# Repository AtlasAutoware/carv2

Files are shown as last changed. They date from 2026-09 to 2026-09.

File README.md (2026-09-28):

# Atlas car v2

The second Atlas Autoware car: a Traxxas Slash 4x4 with a Holmes Hobbies Puller Pro 540 motor, a
SICK TiM561 lidar and a LUCID Triton camera, rebuilt so that almost nothing is wired by hand. Two
custom circuit boards stack on a carbon-fibre-printed deck:

- **Drive board (ATLAS-DRV-1).** The ESC (VESC firmware, same UART commands as car 1), a battery
  protector for a built-in 4S3P 18650 pack, USB-C charging, the servo supply, the lidar's power
  switch and a USB hub.
- **Brain board (ATLAS-BRN-1).** A Jetson Orin Nano carrier forked from Antmicro's open-source
  design, with PoE for the camera and a second Ethernet port for the lidar.

Day to day the car needs one USB-C cable: a 65 W laptop charger charges it, and a laptop on the same
port reaches the Jetson, the ESC and the serial console.

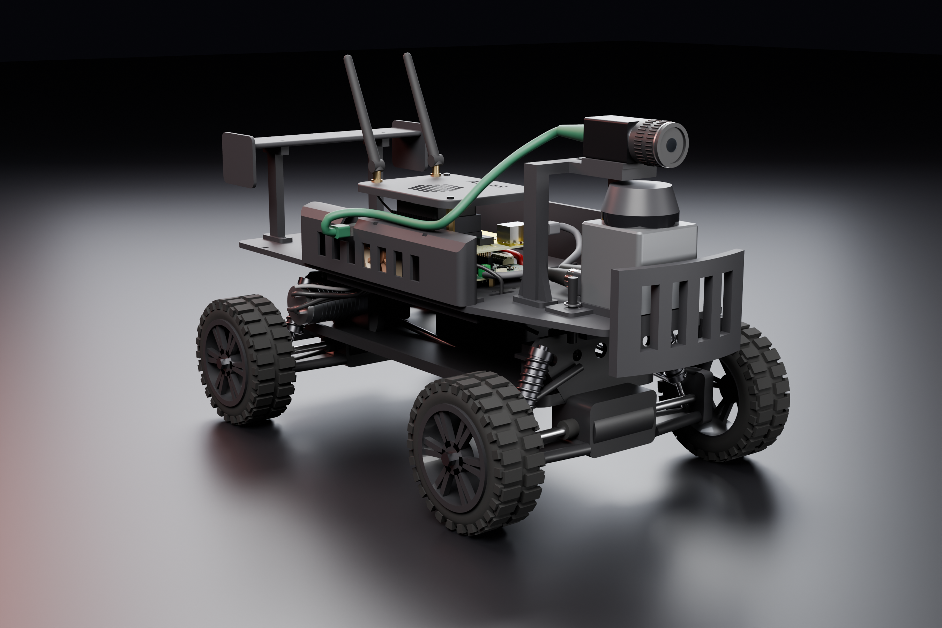
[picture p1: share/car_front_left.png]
car v2, rendered on a stand-in Slash 4x4


## What is in here

| folder | what |
| --- | --- |
| `docs/` | `ARCHITECTURE.md` (the whole design and why), `SOFTWARE.md` (what runs on the boards), `FLASHING.md` (programming the assembled boards), `TPS25751_CONFIG.md` (USB-C charger settings), `PACK_BUILD.md` (building the 18650 pack), `MEASURE_FIRST.md` (chassis numbers to check before printing), `COMPLETE_CAR.md` (the parts that finish the car), `WIRING.md` (every cable run and its length) |
| `boards/drive/`, `boards/brain/` | the two boards: `design.py` is the circuit, `layout.py` the placement and hand-drawn copper, and the KiCad schematics and layouts are generated from them |
| `boards/stack/` | the pin map of the connector between the two boards, used by both |
| `boards/tools/` | the scripts that build, route and check the boards |
| `boards/*/out/fab/` | Gerbers, drill files, pick-and-place and BOM for ordering |
| `firmware/vesc/` | the VESC hardware target for the drive board, `build.sh`, and a prebuilt image in `prebuilt/` |
| `software/jetson/` | the `atlas` command, services and settings for the Jetson (`system/install.sh`), with tests |
| `software/ros2/` | `atlas_power`: battery, E-stop, charging and lidar power in ROS 2 |
| `mech/` | the printed kit: `kit.py` (deck, pods, mounts, pack box) and `extras.py` (stack canopy, bench stand, plugs and cable paths), the STL/STEP files, renders and its own README |
| `sim/` | circuit and thermal checks run on the finished schematics, with their own README |
| `bom/` | the parts list with prices and the cost summary |
| `share/` | pictures for posting; `car_scene.py` and `render_car.py` render the whole car |

## Cost

From `bom/cost_summary.md` (prices from September 2026):

| | USD |
| --- | ---: |
| Drive board: 5 boards, 1 of them assembled | 525.70 |
| Brain board: 5 boards, 1 of them assembled | 563.90 |
| 18650 pack materials | 134.20 |
| Camera lens | 144.00 |
| Charger, cable, fan, thermal pad, hardware, antennas | 124.35 |
| **New purchases** | **1,492.15** |
| Jetson dev kit and NVMe (already on the purchase list) | 459.00 |
| **Car 2 total** | **1,951.15** |
| If needed: M12 camera cable ($30), spot welder ($304.51) | up to 2,285.66 |

The carbon-fibre filament and the aluminium heat spreader (SendCutSend credit) are not in these
numbers because the team already has them.

## Status

On 27 September 2026 the design is finished and nothing has been ordered. Later that day the whole car went into
one model, with every plug and cable. That found two things that could not have been assembled as drawn, now
fixed, and added a canopy over the boards with the Wi-Fi antennas and a bench stand (`docs/COMPLETE_CAR.md`).

- Both boards are routed. KiCad's DRC finds no unconnected nets and no clearance errors on
  either of them. What it still lists is minor: silkscreen warnings on both boards, one 0.2 mm
  track end on the drive board, and on the brain board the footprint-library differences that
  come with Antmicro's design and the courtyard and hole overlaps Antmicro excluded.
- The stack header matches on both boards: all 40 pins carry the same net at the same place, and
  the brain board's corner holes sit over the drive board's (`boards/tools/check_stack.py`).
- The precharge simulation changed the precharge resistors. The bulk capacitors changed too: the
  first choice was tall enough to hit the brain board's SSD (`sim/README.md`).
- The printed kit passes its interference checks. Print the two fit coupons first.

What to check before ordering, and the layout choices that are not obvious from the schematics,
are at the end of `docs/ARCHITECTURE.md`.

## Rebuilding

- Boards: KiCad 10 and Python 3. `boards/tools/run_kicad.sh` runs every step (schematic, board,
  routing export and import, DRC, renders, fabrication files).
  `boards/tools/run_kicad.sh drc-drive fab-drive` checks the finished drive board and writes its
  fabrication files. Careful with `pcb-drive`: it builds the board again from the placement,
  without the routing. The routing itself was done with Freerouting 1.9 and finished with
  `boards/tools/mazeroute.py`.
- Printed kit: `pip install cadquery ezdxf matplotlib`, then `python3 mech/kit.py` and `python3 mech/extras.py`.
- Whole-car renders: `python3 share/car_scene.py`, then `python3 share/render_car.py -- car_front_left car_exploded`
  with Blender 4.2's `bpy` module (Python 3.11, `pip install bpy==4.2.0`) and the board models from
  `run_kicad.sh glb-drive glb-brain`.
- Simulations: ngspice and Python with numpy, scipy and matplotlib; `sim/run_all.sh`.
- Firmware: `firmware/vesc/build.sh` (clones VESC 6.06, adds the two target files, builds; needs
  `arm-none-eabi-gcc`). A build of the committed sources is in `firmware/vesc/prebuilt/`.
- Jetson tools: `sudo software/jetson/system/install.sh` on the car; tests with
  `cd software/jetson && python3 -m pytest tests` (needs `pytest`).

## Licenses

The brain board is derived from Antmicro's Jetson Orin Baseboard (Apache-2.0); its schematic and
board keep Antmicro's notices, and `boards/brain/vendor/antmicro/fetch.sh` downloads the original. The VESC
hardware target is derived from the VESC firmware (GPL-3.0), so those two files are GPL-3.0.

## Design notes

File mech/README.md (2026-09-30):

# Printed kit

The kit is one CadQuery script, `kit.py`. It builds every part and places it on a keep-out model of the
Slash 4x4. Then it checks every pair of solids for overlap, slices the lidar scan plane, exports STEP and STL
(and a DXF for the aluminium heat spreader), and renders PNGs.

`extras.py` builds on it and adds the parts that finish the car: the stack canopy with the Wi-Fi antennas, the
wheels-off bench stand, the mating plugs, and every cable as a path through the model. It checks all of them
against the kit and writes `out/extras_report.json`. The cable lengths from that report are in
`../docs/WIRING.md`, and `../docs/COMPLETE_CAR.md` explains each addition.

    pip install cadquery ezdxf matplotlib
    python3 kit.py                 # about 3 minutes; writes out/ and out/kit_report.json
    UNDER_CLEARANCE=42 python3 kit.py    # any number in P can be overridden the same way
    python3 extras.py              # about 1 minute; canopy, bench stand, plugs and cables, out/extras_report.json

Last run (27 September): zero interference between any two printed parts, bought parts (boards and their tall
components, sensors, cells) or chassis keep-outs. `extras.py` also finds zero between the new parts, the
plugs, the cables and all of those.

Two changes that day came out of modelling the plugs and cables:

- The right side pod's fan moved forward, and a slot through the pod now lets the camera's RJ45 plug out.
- The servo-lead slot in the deck moved clear of the front splice plate.

The only solids that cross the lidar's scan plane (the camera arch legs, the wing, and from `extras.py` the
canopy, its standoffs, the antennas and two cables) sit inside its 90 degree blind sector at the rear. Scan
plane 68.5 mm above the deck, camera axis 122 mm above the deck, pack box inside the battery bay
with 2.8 mm under it. Tightest fit in the board stack: the brain board's NVMe SSD sits 2.4 mm above
the drive board's bulk capacitors.

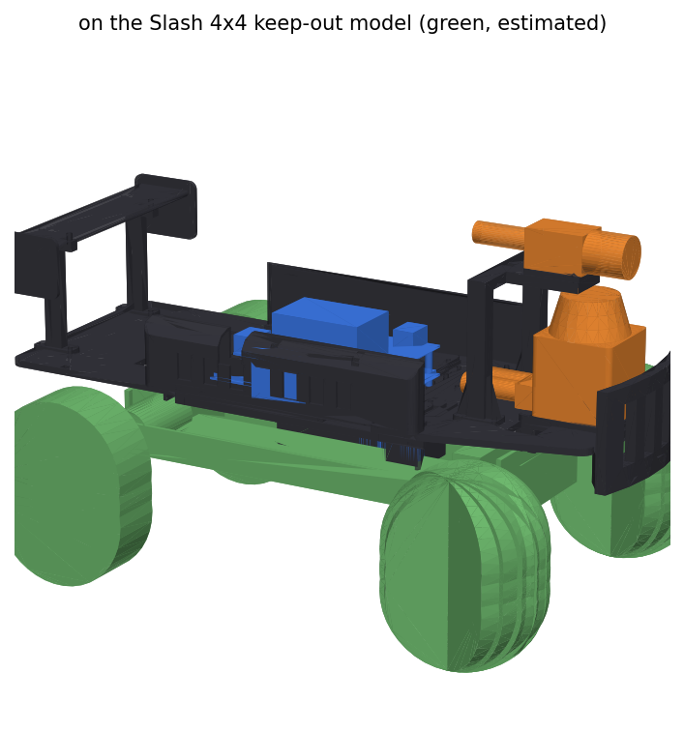
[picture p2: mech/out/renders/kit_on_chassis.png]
kit


## Parts

**Before printing, read [PRINTING.md](PRINTING.md):** several STLs in `out/stl` are not in a printable orientation (the bumper failed on Sept 30). It lists which parts to flip and which need supports.

Sizes are as they sit on the bed (mm). Mass is for solid PETG-CF; with 4 walls and 35 %
gyroid expect about 65 % of it. Everything fits a 250 x 250 bed (Bambu P1S: 256).

| part | print | bed size | solid mass | orientation, notes |
| --- | --- | --- | --- | --- |
| `fit_coupon_front`, `fit_coupon_rear` | 1 each, FIRST | 56-58 x 132 x 25 | 55 / 57 g | top face down, like the deck. Strips of the deck across the towers and body posts: test the saddles and post slots on the real car. Both on one plate: 2 h 30 min, 67 g (P1S, 35 % gyroid) |
| `deck_rear`, `deck_mid`, `deck_front` | 1 each | 146-162 x 178 x 15-25 | 182 / 158 / 171 g | top face down; saddles and ribs point up, no supports. The three pieces butt together and bolt to splice plates underneath |
| `splice_rear_left`, `_right`, `splice_front_left`, `_right` | 1 each | 30 x 72 x 3 | 8 g | flat; 6 x M3 bolts + nylocs each, across the joint |
| `lidar_plinth` | 1 | 70 x 64 x 6 | 24 g | pocket face down; 2 x M3 x 6 into the TiM561's bottom threads (2.0 mm engagement, SICK allows 2.8) |
| `bumper` | 1 | 62 x 124 x 74 | 113 g | flange down; bolts up through the deck into the plinth (4 x M3 x 16) |
| `camera_arch` | 1 | 80 x 102 x 104 | 83 g | feet down; the tongue is a 34 mm bridge |
| `camera_cradle` (0 deg), `_down5`, `_down10` | pick one | 43 x 34 x 4-8 | 7 g | flat; slotted +-1.5 mm for the camera's M3 holes |
| `side_pod_left`, `side_pod_right` | 1 each | 225 x 25 x 50 | 80 / 68 g | outer face down, vents vertical; the right pod holds the 40 mm fan and has the slot the camera plug goes out through |
| `wing_blade` | 1 | 55 x 190 x 46 | 72 g | endplates up |
| `wing_strut_left`, `_right` | 1 each | 35 x 88 x 14 | 16 g | on their side |
| `pack_box` | 1 | 138 x 51 x 72 | 67 g | open end up |
| `pack_lid` | 1 | 138 x 51 x 4 | 27 g | ribs up |
| `cell_holder_bottom`, `_top` | 1 each | 120 x 40 x 5 | 12 g | pockets up |
| `post_washer` | 4 | 30 x 30 x 3 | 3 g | body clips sit on these above the deck |
| `stack_canopy` (extras.py) | 1 | 128 x 99 x 6.4 | 41 g | top face down, no supports; cover over the board stack with the antenna jacks and the fan grille |
| `bench_stand` (extras.py) | 1, PLA | 173 x 123 x 128 | 267 g solid (PETG-CF density) | pad face down; a workshop tool, not on the car |

Total about 1.2 kg solid, about 0.8 kg of filament as printed.

## Material and settings

CF-filled filament is abrasive: use a hardened-steel nozzle (0.4 or 0.6 mm), and dry the
spool first.

| part | material | settings |
| --- | --- | --- |
| deck halves, plinth, arch, wing struts | PETG-CF (or PA-CF if the printer has an enclosure and a dry box) | 0.2 mm layers, 4 walls, 35 % gyroid, 5 top/bottom |
| bumper | PETG-CF; PA-CF is tougher in a crash | 5 walls, 40 % gyroid |
| side pods, wing blade, pack lid | PETG-CF | 3 walls, 20 % gyroid |
| pack box, cell holders | PETG-CF or plain PETG | 3 walls, 30 %; holders at 100 % so the pockets stay round |

Do not rely on CF-filled plastic as electrical insulation: carbon fibre conducts. The pack
has fish paper and Kapton for that.

## Hardware

- M3 brass heat-set inserts (4.0 mm hole, 5 mm deep), about 30 in the deck and the sensor mounts:
  drive board standoffs 6, pack box 6, camera arch 4, side pods 5, wing 4, plinth 4. Buy 50.
- Deck joints: 24 x M3 x 12 socket screws and nylocs through the deck and the four splice plates.
- Board stack: 6 x M3 7 mm male-female standoffs from the deck inserts to the drive board
  (holes H1001-H1004, H1007, H1008), and 4 x M3 20 mm male-female standoffs from the drive board
  to the four corners of the brain board. Over H1002 and H1004 the 20 mm standoff screws through
  the drive board into the 7 mm one below it; over H1005 and H1006 it is held by an M3 nut under
  the drive board. Four M3 x 6 screws on top of the brain board, four more on the drive board's
  other deck holes.
- Heat spreader: 3/16 in (4.76 mm) 6061, 60 x 48 mm, cut from `out/dxf/heat_spreader.dxf`. Order it
  with the four 2.5 mm holes tapped M3. Four M3 x 8 screws come up through the deck into it. The
  notch at one corner makes room for the H1005 nut. A 1.0 mm thermal pad goes between the spreader
  and the bottom of the FETs.
- M3 socket screws 6-16 mm for the rest, and the chassis's own body clips over the post washers.
- Canopy: 3 x M3 40 mm male-female standoffs. They replace the M3 x 6 top screws at three of the brain board's
  corners (brain-local (115.06, 5.06), (6, 84) and (114, 84)); the fourth corner sits under the camera RJ45.
  3 x M3 x 6 button-head screws hold the canopy on them.
- Two RP-SMA antennas and two pigtails from the Wi-Fi card to the canopy, and zip ties (`../docs/WIRING.md`).

## Assembly order

1. Heat-set all inserts. Bolt the three deck pieces to the splice plates.
2. Pack: build it (`docs/PACK_BUILD.md`), drop the box into the bay through the deck window,
   lid on.
3. Deck onto the towers, posts through the slots, washers and body clips on.
4. Lidar screwed to the plinth on the bench; plinth, deck and bumper bolted together from
   below.
5. Camera arch, cradle, camera.
6. Heat spreader (screwed to the deck from below) and thermal pad, 7 mm standoffs, drive board.
   Wire the lidar power terminal (J902) now: its screws end up under the brain board's front edge.
7. 20 mm standoffs, then the brain board. Clip the two Wi-Fi pigtails onto the M.2 card before the Jetson
   module goes on, because the card sits under it.
8. Side pods, fan, wing. Plug in the list in `docs/ARCHITECTURE.md`; the camera plug goes out through the slot
   in the right pod. The runs are in `docs/WIRING.md`.
9. The 40 mm canopy standoffs, then the canopy, with the pigtails' RP-SMA jacks nutted into its two holes.
   Screw the antennas on last.

## What the model does not know

Every chassis dimension is an estimate carried over from car 1 until it is measured
(`docs/MEASURE_FIRST.md`). The camera's bottom hole spacing is an estimate. The TiM561's
swivel-unit and plug sizes are estimates (the SICK drawing does not give them).

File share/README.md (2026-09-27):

# Pictures for posting

All of these come out of the design files; none are photos.

| file | what it shows |
| --- | --- |
| `car_front_left.png`, `car_rear_right.png`, `car_side.png`, `car_top.png` | The whole car: the printed kit with the stack canopy, both boards, the pack, every cable and plug, on a stand-in Slash 4x4. Rendered with Blender Cycles by `render_car.py` from the scene `car_scene.py` builds out of `mech/kit.py`, `mech/extras.py` and the two boards' KiCad 3D models. |
| `car_exploded.png` | The same, with the drive board lifted 55 mm, the brain board 115 mm and the canopy 185 mm to show the stack. The cables are hidden in this one, and the antennas are folded back. |
| `drive_iso.png`, `drive_top.png`, `drive_bottom.png` | The drive board as routed, rendered by KiCad. The four bulk capacitors, the 2 x 20 stack socket and the power stage (FETs on the underside) are the big parts. |
| `brain_iso.png`, `brain_top.png` | The brain board (Jetson carrier) as routed, rendered by KiCad. The Jetson module and the NVMe card plug in and are not shown. Many of the parts from Antmicro's design, the module socket among them, have no 3D model here and show as bare pads. |
| `drive_thermal_70A.png` | Simulated temperature of the drive board at 70 A peak phase current with the fan, 35 C air: about 58 C on the hottest FET (`sim/drive_thermal.py`). |
| `dclink_waveforms.png` | Simulated ripple current in the ESC's bus capacitors (`sim/dclink.py`). |
| `precharge.png` | Simulated switch-on of the motor bus through the precharge resistors (`sim/precharge.py`). |
| `poe_boost.png` | Simulated 52 V boost that powers the camera over Ethernet (`sim/poe_boost.py`). |

Stand-ins: in the car pictures the chassis is drawn from `kit.py`'s keep-out numbers (all estimates), with
suspension, wheels and tread drawn to look plausible, not measured. The lidar, the camera and lens, the Jetson
module with the dev kit's heatsink and fan, the NVMe and Wi-Fi cards, the RJ45 jacks and plugs, the stacking
header, the 40 mm fan and the antennas are simple shapes sized from their datasheets or from kit.py's envelopes, not models of
the real parts. In the drive board pictures a few parts have no 3D model in KiCad and show as bare pads.

To make them again:

1. `boards/tools/run_kicad.sh glb-drive glb-brain render-drive render-brain` writes the board models and renders
   to `boards/*/out/render/`; copy the board PNGs you want here.
2. `python3 share/car_scene.py` writes the scene (`share/scene/`, not in git).
3. Render with `python3 share/render_car.py -- car_front_left car_rear_right car_side car_top car_exploded`, using
   Blender 4.2's `bpy` module (Python 3.11). About 12 minutes a view at 2700 x 1800 and 80 samples on two CPU
   cores; `--quick` gives a 900 x 600 preview in under a minute.
4. `sim/run_all.sh` writes the plots to `sim/out/`.

`make_renders.py` is the older VTK version, with no chassis, canopy or cables. It writes the same car file names.

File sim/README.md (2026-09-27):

# Simulations

Checks run on the finished schematics, before anything is ordered. Each one is a short script; `run_all.sh`
runs them all (ngspice and Python with numpy, scipy and matplotlib) and writes the plots and a JSON file per
check to `out/`. Two of them changed the design; the changes are listed at the end.

| script | question | answer |
| --- | --- | --- |
| `dclink.py` | How much ripple current do the ESC's bus capacitors carry? | 3.5 A per capacitor at 30 A peak phase current, 7.6 A at 70 A, 10 A at 100 A. The 12 ceramics take 8-27 A between them, the battery leads about 2 A. |
| `precharge.py` | Does the precharge resistor survive switching the car on? | One 10 Ohm 2512 resistor took 0.29 J in about 10 ms, about 1.5 times its single-pulse rating. Two pulse-proof 22 Ohm resistors in parallel take 0.15 J each, inside theirs. |
| `poe_boost.py` | Is the camera's 52 V supply comfortable at full load? | Inductor peak 0.75 A with the camera (5 W) and 1.6 A at 15 W, against 4.2 A saturation and about 2.4 A current limit. 52 V ripple 80 mV at 5 W, 250 mV at 15 W. |
| `drive_thermal.py` | How hot does the drive board get? | At 70 A peak phase current with the fan: about 58 C on the hottest FET at 35 C air; 70 C at 100 A. Without the fan, 91 C at 70 A. |

## What the numbers rest on

- **Bus ripple (`dclink.py`).** Three ideal half-bridges switch at 30 kHz with sine-triangle PWM, modulation
  0.8, into a motor modelled as 10 mOhm + 20 uH per phase with a sinusoidal back-EMF at 400 Hz. The
  Puller Pro's phase resistance and inductance are not published; 20 uH is typical for a 540-size motor
  and mostly sets the switching ripple in the phase current, not the capacitor current. Capacitors:
  Panasonic EEH-ZU1V331P (330 uF, 11 mOhm, rated 4.8 A rms at 100 kHz and 125 C), twelve Murata
  GRM32ER71H106KA12L (10 uF 50 V X7R, about 6 uF each left at 14 V). Pack 24 mOhm with 150 nH of leads.
- **Precharge (`precharge.py`).** Full pack (16.8 V), 1.4 mF on the bus, and the servo supply switching on
  above 9 V and drawing 0.3 A, which holds the bus about 3 V below the pack until the main FETs close.
  The pulse rating comes from the single-pulse diagrams of the Vishay CRCW-HP series (about 100 W for 1 ms,
  20 W for 10 ms, 2 W for 100 ms, 2512 size) and of IRC's PWC series for a standard part (about half).
- **Boost (`poe_boost.py`).** The power stage only, at the duty cycle that holds 52 V: 47 uH Coilcraft
  XAL7070-473 (84 mOhm), CSD19538Q3A (60 mOhm taken hot), Vishay SS2H10, 3 x 2.2 uF 100 V ceramics (about
  0.9 uF each at 52 V) and a 22 uF aluminium can. The LM5155's loop is not simulated: its datasheet does not
  publish the internal gains a switching model would need. The compensation follows TI's design
  procedure (crossover about 5 kHz). Switching losses are left out, so the efficiency figure in the JSON
  file counts conduction losses only.
- **Temperature (`drive_thermal.py`).** A 0.5 mm grid over the 140 x 90 mm board: in-plane conduction from
  six 2 oz copper layers (90 % copper under the power stage, 50 % elsewhere) and FR4, both faces cooled by
  the side-pod fan's air (h = 25 W/m2K; 8 W/m2K for still air), and the aluminium spreader under the power
  stage coupled through the thermal pad and the FET package tops (taken as 20 C/W). Losses at the chosen
  operating point: FET conduction from the switch RMS currents with 1.2 mOhm hot, switching from
  56 ns edges (2 x 28 nC Qgd at 1 A gate drive), dead-time diode loss, the battery-path FETs and shunts,
  and about 2 W for the rest of the board. 70 A peak phase current is about 33 A from the pack.

These are estimates to find weak spots before building. The bench checks in `docs/ARCHITECTURE.md` (FET
and capacitor temperatures at 50 A and 70 A) still stand.

## Design changes they led to

1. **Precharge resistor.** R319 was one 10 Ohm 2512. It is now R319 + R320, two 22 Ohm Vishay CRCW2512-HP
   pulse-proof resistors in parallel, R320 directly under R319 on the bottom. The STM32 firmware also gives
   up on a precharge whose bus is still under 4 V after 10 ms (a short on the motor bus), because the
   resistors are rated for the charging pulse, not for 13 W each for as long as the old 1 s timeout
   (`firmware/vesc/hw_atlas_drv1.c`).
2. **Bus capacitors.** The 470 uF 35 V part turned out to be 16.8 mm tall, which would hit the brain
   board's NVMe SSD. The 330 uF 35 V part of the same series is 12.8 mm tall (2.4 mm clear of the SSD).
   The simulation shows why capacity matters less than ripple current here: at 70 A peak phase current each
   of the four capacitors carries about 7.6 A rms, above the 4.8 A rated at 125 C. That rating is set at
   the capacitor's maximum temperature; at 35-55 C board temperature they will run warm, not fail. Worth a
   thermocouple on one of them during the 70 A bench run.

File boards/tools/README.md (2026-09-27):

# Board tools

These scripts turn `design.py` and `layout.py` into finished KiCad boards. Some of them run inside
KiCad's Python (`flatpak run --command=python3 --filesystem=home org.kicad.KiCad script.py ...`, marked
**K** below). The rest need plain Python with numpy, scipy, shapely, scikit-image and matplotlib
(`pdfpads.py` also needs PyMuPDF). `run_kicad.sh` wraps the KiCad steps, one argument per step:
`run_kicad.sh drc-drive fab-drive`, `run_kicad.sh render-brain` and so on. It works from the folder
it sits in; a first argument ending in `.tar.gz` is a sync tarball in `.work/` to unpack first.
`pcb-<board>` builds a board again from its placement, so on a routed board it throws the routing away.

## Order of work

1. **Schematic.** `build_sch.py` writes the schematic and the parts JSON. It uses `eda.py` for
   schematic capture and `chips.py` for the pin tables. `check_fp.py` checks that every footprint
   exists with the right pads.
2. **Placement.** `placer.py` runs the board's `layout.py` against a footprint model, then places
   the remaining parts next to the pins they connect to. The drive board's layout sets `KEEP_AUTO`
   now that it is routed, so the other parts stay put when one part is moved. The brain board's
   layout pins its parts by hand instead.
3. **Board.** `build_pcb.py` (**K**) builds the board from the placement and the hand-drawn copper
   in `layout.copper()`: escapes, via arrays and pours. `check_copper.py` checks that copper before
   KiCad sees it.
4. **Autorouting.** `dsn_export.py` (**K**) and `dsn_patch.py` feed Freerouting, and
   `ses_import.py` (**K**) brings the result back. `route_prep.py` holds the view of the board that
   the router sees.
5. **Finishing the routing.** `dump_board.py --route-view` (**K**) writes the board to JSON.
   `mazeroute.py` then routes what is still open: coupled differential pairs first, then everything
   else in negotiated rounds. It works on the dump and writes a routes JSON, which `add_routes.py`
   (**K**) applies. Its docstring lists the options.
   - `strip_routes.py` and `strip_box.py` (**K**) take routed copper off so it can be routed again.
   - `move_parts.py` (**K**) moves parts on a routed board to their new placement.
   - `update_zone.py` (**K**) gives a pour a new outline.
   - `zone_islands.py` (**K**) lists which pieces of a pour touch what.
   - On the drive board, the last few ground pads left in islands of the outer ground fill were
     joined by hand: a via or a short track each, checked for clearance before it went on. The board
     file holds the result.
6. **Finish.** Run these in order, then run DRC (`drc-<board>`); it should show no unconnected
   items and no clearance errors.
   - `pad_vias.py` (**K**) gives each unconnected pad a via into its plane. Other modes:
     - `--ep REF.PAD` adds a via grid inside exposed pads.
     - `--pads` works on pads you name.
     - `--through-pours` lets a via go through another net's pour.
     - `--zone-islands` gives stray pieces of pour a via.
   - `finish_pcb.py` (**K**) adds GND stitching vias, cleans up the silkscreen and swaps in 3D models.
   - `clean_tracks.py` (**K**) splits T-joins and tracks that run on past a via or pad, then removes
     dead-end tracks and vias, including vias that only join tracks on one layer.
   - `set_netclasses.py` writes the net classes into the project file.
7. **Outputs.** `run_kicad.sh fab-<board>` writes Gerbers, drill files, CPL and BOM.
   `render-<board>` and `glb-<board>` write the pictures and the 3D model.
   `check_stack.py` checks the connector between the two boards.

The brain board starts from Antmicro's board rather than step 3: `fork_pcb.py` (**K**) deletes the
removed parts, renets the rest and places the new ones.

## Helpers

- `plot_geom.py` and `plot_copper.py` plot a placement and the hand-drawn copper.
- `fpinfo.py` prints a footprint's pads.
- `pdfpads.py` reads pad sizes off TI land-pattern PDFs, for `make_footprints.py`.
- `sexp.py` reads and writes KiCad files.
- `pack_sync.sh` packs the sources for the KiCad machine. It is specific to how these boards were
  built and has a hard-coded path (the build container's copy of the repo).

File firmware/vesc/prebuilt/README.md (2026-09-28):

# Prebuilt ATLAS_DRV1 firmware

Built by `firmware/vesc/build.sh --system` from the commit named in `BUILD_INFO.txt`. Not yet
run on a board.

- `atlas_drv1_full.hex`: firmware (0x08000000) + VESC bootloader (0x080E0000). The first flash
  of a blank STM32, over SWD (docs/FLASHING.md, step 1). Needed once so that VESC Tool can
  update the firmware later.
- `atlas_drv1.bin`: the firmware alone, for VESC Tool (Firmware, Custom File).

Rebuild after any change to `hw_atlas_drv1.c` or `.h` and replace these files.

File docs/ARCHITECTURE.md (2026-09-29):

# Car v2: integrated electronics and printed kit

Design for the second Atlas car on the Traxxas Slash 4x4 (6822 chassis, the one with the
"KA2246-R00" label and the Holmes Hobbies Puller Pro 540 2200 kV motor). The aim: plug in as
few things as possible. Everything that can live on a circuit board does, the battery is
built in and charges over USB-C, and the body is printed in carbon-fibre filament in the
style of the Neobotics NeoRacer.

Status on 2026-09-27: see [Status and next steps](#status-and-next-steps) at the end. In short,
both boards are designed and routed and pass KiCad's DRC with no unconnected nets and no
clearance errors; the printed kit is modelled and checked; nothing has been ordered.

## What you plug in

Once, when building the car:

| connection | to | how |
| --- | --- | --- |
| 18650 pack, power | drive board B+ / B- pads | two 10 AWG leads, soldered |
| 18650 pack, cell taps + temperature | drive board | one 7-pin JST-XH |
| motor phases | drive board | three 12 AWG pigtails soldered to the board, 4 mm bullets to the motor |
| motor hall sensor | drive board | the motor's own 6-pin sensor lead (JST-ZH assumed, confirm on the motor) |
| steering servo | drive board | the servo's own 3-pin lead |
| lidar power | drive board | the donor M12 power cable into a 2-pin terminal |
| lidar Ethernet | brain board RJ45 #2 | the donor M12-D to RJ45 cable |
| camera | brain board RJ45 #1 | one M12 X-coded to RJ45 cable: data and PoE power together; the plug goes out through the slot in the right side pod |
| Jetson fan, side-pod fan | brain board / drive board | their own leads |
| Wi-Fi antennas | M.2 Wi-Fi card | two MHF4 pigtails to the RP-SMA jacks in the stack canopy (the dev kit's AW-CB375NF card has MHF4 jacks) |
| E-stop loop (optional) | drive board | 2-pin JST-PH, normally closed; a jumper if unused |

Every run, its length and its route are in `docs/WIRING.md`. The parts that finish the car (the stack canopy,
the bench stand, and the fixes that came out of modelling the plugs) are in `docs/COMPLETE_CAR.md`.

Every day: **one USB-C cable.** A 65 W USB-C charger charges the car. A laptop on the same
port reaches the Jetson (USB networking and flashing), VESC Tool on the ESC and the Jetson's
serial console, and keeps the car alive while you work.

Compared with car 1, this removes the XT90 Y-harness, the separate ESC and its USB lead, the
PD trigger cable and barrel jack, the power bank, the BEC and its fused tap, the PCA9685 board,
the USB hub and every USB sensor cable. The two boards plug into each other.

## System

```mermaid
flowchart LR
  subgraph PACK["4S3P 18650 pack (12 x Molicel P28A, 8.4 Ah)"]
    CELLS["cells + nickel"]
  end
  subgraph DRV["drive board ATLAS-DRV-1 (140 x 90 mm, 6 layers, 2 oz)"]
    BMS["BMS BQ7791508<br/>low-side FETs, 0.5 mOhm sense"]
    CHG["USB-C PD TPS25751D<br/>+ charger BQ25798"]
    SW["main switch TPS48111<br/>precharge, 1.2 us short-circuit cut"]
    BTN["power latch<br/>SN74LVC1G74 + TPS70933"]
    ESC["ESC: STM32F405 + DRV8323RS<br/>12 x CSD18510Q5B, VESC firmware"]
    SRV["servo 7.5 V 8 A<br/>TPSM63610"]
    LID["lidar eFuse TPS26600 1 A"]
    HUB["USB2514B hub + CP2102N"]
    IMU["LSM6DS3TR-C IMU"]
  end
  subgraph BRN["brain board ATLAS-BRN-1 (Jetson carrier, 120 x 90 mm, 8 layers)"]
    EF["input eFuse TPS259474"]
    SOM["Jetson Orin Nano module<br/>on SO-DIMM"]
    NVME["M.2 NVMe"]
    WIFI["M.2 Wi-Fi"]
    POE["52 V boost LM5155<br/>+ PoE PSE TPS23861"]
    LAN["LAN7800 USB-to-Ethernet"]
  end
  CELLS --> BMS --> SW --> ESC --> MOTOR["Puller Pro 540<br/>2200 kV, halls"]
  SW --> SRV --> SERVO["INJS235 servo"]
  BMS --> CHG
  USBC["USB-C: charger or laptop"] --> CHG
  USBC --> HUB
  CHG -- "VSYS 12-16.8 V" --> EF --> SOM
  CHG -- VSYS --> LID --> TIM["SICK TiM561"]
  EF --> POE --> CAM["LUCID Triton<br/>PoE, GigE"]
  SOM -- "GbE" --> CAM
  SOM -- "USB 2" --> LAN --> TIM
  HUB -- "USB 2" --> SOM
  HUB --> ESC
  SOM -- "UART 115200" --> ESC
  BTN --> SW
  IMU --> ESC
```

Why two boards and not one: the ESC and battery path need thick copper (2 oz) and carry
70-150 A; the Jetson carrier needs eight layers with impedance-controlled pairs for PCIe and
USB and fine pitch for the 260-pin module socket. One board would have to be both, which makes
the whole thing expensive and hard to route. Stacked, they plug together through a 2 x 20
header with no wires, each can be tested alone, and if the carrier has a bug the Jetson module
goes back on its NVIDIA dev-kit carrier while the drive board keeps running the car.

## Power budget

| load | power | source |
| --- | --- | --- |
| Jetson Orin Nano module, 25 W mode, + carrier losses | about 27.5 W | NVIDIA power modes; 10 % carrier loss assumed |
| NVMe SSD | about 3.5 W peak | typical M.2 NVMe |
| Wi-Fi card | about 2 W | typical |
| LAN7800 | about 1 W | typical |
| SICK TiM561 | 4 W typical | SICK datasheet 1071419 |
| LUCID Triton over PoE | 3.1 W at the camera, about 4 W with the boost and PSE losses | Edmund Optics listing for TRI023S-CC |
| drive board logic, fans | about 3 W | estimate |
| **compute rail total** | **about 45 W: 3.1 A at 14.4 V, 3.7 A at 12 V** | |
| motor | 70 A continuous, about 150 A bursts | team's own logs |
| servo | 7.5 V, up to 8 A (10 A peak) | TPSM63610 rating |

Pack: 4S3P Molicel P28A = 14.4 V nominal, 16.8 V full, 8.4 Ah, about 121 Wh, 105 A maximum
continuous (35 A per cell, 18650batterystore.com). That is above 100 Wh, so flying with it
needs airline approval (the 100-160 Wh class). With the car parked and everything on (45 W)
it runs about 2.5 hours; driving time depends on how hard the motor works.

Charging: the BQ25798 accepts 3.6-24 V at up to 3.3 A on VBUS and charges at up to 5 A
(BQ25798 datasheet, recommended operating conditions). The input limit is set to 3.25 A, so a
65 W charger at 20 V is the most it can use. With the car off, about 60 W goes into the pack:
roughly 2.5 hours from empty. With the car on, the compute rail takes about 45 W of the 65 W, so
the pack charges slowly while you debug. A laptop port (5 V, 7.5-15 W) keeps the car alive on
the bench but will not fully charge it.

## Drive board (ATLAS-DRV-1)

140 x 90 mm, 6 layers, 2 oz copper on every layer, ENIG. Sources in `boards/drive/`: `design.py` is the
circuit (every part with the reason for its value), `layout.py` the placement and the
hand-drawn copper, and the KiCad files are generated from them. The board stands on six 7 mm
standoffs on the printed deck. The ESC power stage is on its underside and presses through a
1 mm thermal pad onto an aluminium heat spreader, with a 40 mm fan in the right side pod
blowing across it.

**Battery protection.** TI BQ7791508: a 3-5S protector that needs no microcontroller, with
cell balancing. This variant trips at 4.20 V over-voltage and 3.00 V under-voltage per cell,
over-temperature 65 C, and recovers from current faults on its own. It drives low-side charge
and discharge FETs (4 + 4 CSD18510Q5B) in the pack's negative lead. Its current thresholds are
voltages across the sense resistor, so the 0.5 mOhm four-terminal shunt (Isabellenhuette BVR,
4026) sets them: OCD1 70 mV = 140 A for 1.4 s, OCD2 140 mV = 280 A for 0.7 s, short circuit
300 mV = 600 A for 0.4 ms, charge over-current 60 mV = 120 A. The VESC input-current limit
(90 A) keeps normal driving under OCD1.

**Main switch and precharge.** A TI TPS48111 high-side driver switches the motor bus through
four CSD18510Q5B, with a 0.2 mOhm shunt. The STM32 sequences it: first the precharge FET, which
charges the ESC capacitors through two pulse-proof 22 Ohm resistors in parallel (time constant
about 16 ms), then, once the bus voltage has come up, the main FETs. No spark and no BMS
short-circuit trip at switch-on. If the bus is still under 4 V after 10 ms, something on it is
shorted, and the firmware gives up rather than cook the resistors. The TPS48111 cuts a
short circuit (350 A) in 1.2 us and an overload (150 A for 10 ms) on its own, retries after
15 s, and reports the bus current to the MCU.

**Power button.** A TPS70933 LDO keeps a 3.3 V always-on rail from the pack (1 uA). An
SN74LVC1G74 flip-flop is the on/off latch: a press of the on-board button (or a remote button
on the 2-pin connector) sets it, which turns on the main switch and the 5 V buck. The MCU turns
the car off by clearing the latch (KILL, PB12), after the Jetson has shut down. A crash or reset
of the MCU does not turn the car off. The same press wakes the charger out of ship mode.

**USB-C charging.** TI TPS25751D USB PD controller (integrated sink switch) plus TI BQ25798
buck-boost charger. The TPS25751D loads its configuration from a 64 KB I2C EEPROM (M24512),
negotiates up to 20 V and programs the BQ25798 over I2C with no MCU. The EEPROM image is made
with TI's Application Customization Tool (settings in `docs/TPS25751_CONFIG.md`), and the Jetson
writes it through the controller's own I2C port (`atlas pd flash`); the 4-pin header J702 stays unfitted. The
BQ25798 is set for 4S and 1.5 MHz by its PROG resistor, with the input limit at 3.25 A. Its
SYS output (NVDC power path) is the compute rail, VSYS, so the Jetson and the lidar run from
USB power whenever it is plugged in. The pack's NTC goes to the BMS; the charger's TS input sees
a fixed 25 C divider.

**One cable for debugging.** The USB-C data pins go to a Microchip USB2514B hub. Port 1: the
Jetson's USB0 (L4T USB networking at 192.168.55.1). Port 2: the STM32's USB (VESC Tool).
Port 3: a CP2102N bridge to the Jetson's debug UART (boot log and console). A FLASH slide
switch and two TS3USB30E switches connect the USB-C port straight to the Jetson's USB0
instead, because NVIDIA asks for a direct link in recovery mode. These five high-speed links
are routed as coupled pairs (0.15 mm tracks, 0.15 mm gap, 0.2 mm to everything else). The
width for 90 Ohm depends on the stack-up actually ordered, so check it in JLCPCB's impedance
calculator before ordering and ask for impedance control.

**ESC.** A VESC-6-class design: STM32F405RGT6 and TI DRV8323RS gate driver (three
current-sense amplifiers, gain 40 V/V, and a small buck that makes the board's 5 V), twelve
CSD18510Q5B (40 V, 0.79 mOhm typical at 10 V; TI datasheet SLPS632), two per switch, three
0.2 mOhm low-side shunts (range +-206 A), 4 x 330 uF hybrid polymer bulk capacitors plus
12 x 10 uF ceramics next to the FETs. Conduction loss at 70 A with the FETs hot
(1.5 x Rds(on)): 3 x 70^2 x 0.6 mOhm = about 9 W, plus a few watts of switching. The board
keeps the Trampa HD60 pin map on purpose, so the firmware change is small:
`firmware/vesc/hw_atlas_drv1.{h,c}` (derived from `hw_hd60`, GPL-3.0). The changes: the IMU's
SDA moves off PB2 so BOOT1 stays low for the ROM bootloader, the power-hold pin becomes KILL,
and PA4-PA7, PC10, PC14 and PC15 carry the new brain-power, current, precharge, E-stop and
Jetson-handshake signals. The target builds with the VESC 6.06 tree (`firmware/vesc/build.sh`). The Jetson talks to it on
USART3 at 115200 baud, the same as car 1, so `vesc_driver` does not change.

**Other outputs.** Servo: TI TPSM63610 power module (integrated inductor, 8 A, 10 A peak) set
to 7.5 V from the switched motor bus, on above 9 V, with 4 x 47 uF plus 220 uF polymer on its
output for stall pulses; the signal comes from the VESC servo output through a 5 V buffer.
Lidar: TI TPS26600 eFuse at 1 A from VSYS into a 2-pin terminal, off until the Jetson enables
it, so the Jetson can power-cycle the lidar. Fan: 5 V, 4-pin header, full speed.

**Sensing and safety.** LSM6DS3TR-C IMU on the VESC's bit-banged I2C (the VESC `lsm6ds3`
driver). TI INA228 on the BMS shunt gives the Jetson pack voltage, current and energy over I2C.
SN65HVD230 for a spare CAN port with a termination jumper. E-STOP: a normally-closed 2-pin loop
AND-ed in hardware (74LVC1G08) with the MCU's gate-enable pin into the DRV8323's ENABLE, so
opening the loop (a big red button or a wireless relay) stops the motor even if the firmware
is hung.

## Brain board (ATLAS-BRN-1): the Jetson carrier

120 x 90 mm, 8 layers, impedance-controlled, ENIG. It is a fork of Antmicro's open-source
Jetson Orin Baseboard (github.com/antmicro/jetson-orin-baseboard, Apache-2.0, 120 x 60 mm):
the hard high-speed layout around the module socket, the M.2 slots and the module supply is
kept exactly as Antmicro routed it, and the board grows by a 30 mm strip for the new circuits.
`boards/brain/fork_config.py` lists every change; `fork.py` and `tools/fork_pcb.py` apply them
to Antmicro's schematic and board.

Kept: SO-DIMM module socket, module power section, M.2 Key M (2280 NVMe), M.2 Key E (Wi-Fi),
the RJ45 with its magnetics, RTC backup, fan header, reset and recovery buttons, the I/O
expander.

Removed: both CSI camera connectors (the camera is GigE), HDMI, the USB-C debug/DisplayPort
port and the USB 3 USB-C port with their PD controller (charging and USB live on the drive
board), the DC barrel input, the PoE powered-device front end, and the expansion socket.

Added:
- **Board input.** A TPS259474 eFuse takes VSYS from the stack header when the drive board
  raises POWER_EN, limits it to 5 A, turns off above 19.2 V and soft-starts the module supply.
- **PoE for the camera.** A TI LM5155 boost makes 52 V from VSYS (300 kHz, 47 uH Coilcraft
  XAL7070, CSD19538Q3A switch), and a TI TPS23861 IEEE 802.3at PSE, running in its automatic
  mode, powers port 1 on the centre taps of the RJ45 that already carries the module's Gigabit
  Ethernet. The Triton needs IEEE 802.3af and draws 3.1 W. This replaces the AC PoE injector
  the camera needed.
- **Second Ethernet for the lidar.** A Microchip LAN7800 USB-to-Gigabit bridge on the module's
  USB 2 pair (the one Antmicro used for the USB-C port), with its own RJ45. The TiM561 is
  100BASE-TX; the stock L4T kernel has the `lan78xx` driver. The chip is turned so its
  Ethernet pins face the jack: the four pairs run straight to it as 100 Ohm pairs and the USB 2
  pairs as 85 Ohm pairs, with the widths and gaps Antmicro set for this stack-up.
- **Stack header.** 2 x 20, 2.54 mm long-pin header on the underside mating the drive board's
  socket. The module's UART is 1.8 V, so an NTS0102 shifts it to the STM32's 3.3 V. The
  expander pins that drove the removed camera and USB-C switches now carry the drive board
  signals (STM32 reset and BOOT0, lidar enable, E-stop and charger status).

The module from the Orin Nano Super dev kit moves over with its heatsink and fan. The
dev-kit carrier stays in the drawer as the fallback.

## Stack header (drive board to brain board)

The brain board stands 20 mm above the drive board on four M3 standoffs, one at each corner.
The connector is a Samtec SSQ-120-03-G-D socket on the drive board and a TSW-120 long-pin
header on the brain board. `boards/stack/stack.py` defines the pin map once for both boards;
`boards/tools/check_stack.py` checks both finished boards against it (nets, pin positions, and
that each brain-board corner hole sits over a drive-board hole).

| pins | signal | direction | note |
| --- | --- | --- | --- |
| 1-6 | VSYS | drive to brain | 12-16.8 V, 6 pins x 3 A |
| 7-10, 13-14, 29-30, 36-40 | GND | | |
| 11, 12 | USB0 D+ / D- | both | Jetson USB0: hub port 1, or straight to USB-C when flashing |
| 15, 16 | VESC UART | Jetson UART1 to STM32 USART3 | 115200 baud, 3.3 V, vesc_driver |
| 17, 18 | console UART | Jetson debug UART to the CP2102N | 3.3 V |
| 19, 20 | I2C SCL / SDA | Jetson I2C1 | INA228, board ID EEPROM, TPS25751 |
| 21 | PWR_BTN_N | drive to brain | power button: the Jetson shuts down |
| 22 | OS_HALTED | brain to drive | high once the module is off; the MCU may cut power |
| 23 | POWER_EN | drive to brain | turns on the brain board's input eFuse |
| 24 | MCU_NRST | brain to drive | the Jetson can reset the STM32 (open drain) |
| 25 | MCU_BOOT0 | brain to drive | the Jetson can start the STM32 bootloader |
| 26 | ESTOP_OK | drive to brain | E-stop loop closed |
| 27 | CHG_STAT | drive to brain | low while charging |
| 28 | LIDAR_EN | brain to drive | TPS26600 enable |
| 31, 32 | spare | | brain-board expander pins; test pads on the drive board |
| 33, 34 | CAN TX / RX | Jetson CAN | 3.3 V; test pads on the drive board |
| 35 | 3V3_DRV | drive to brain | reference for the level shifters |

## The pack

Twelve Molicel P28A (18.6 x 65.2 mm, 46 g) standing upright in a 2 x 6 grid, 4S3P, inside a
printed box in the stock battery bay. With the first and last groups flipped, both main
terminals come out on top, so the leads go straight up through the lid to the drive board.
Details, strip layout and safety: `docs/PACK_BUILD.md`.

## Software changes

Details in `docs/SOFTWARE.md`; programming order in `docs/FLASHING.md`.

- ESC: `firmware/vesc/build.sh` builds the `fw_atlas_drv1` target on VESC 6.06 (it compiles; not
  yet run on a board). First flash over SWD with an ST-Link, then updates from VESC Tool over USB.
  `vesc_driver` keeps working over the UART at 115200 (`/dev/atlas_vesc`).
- Lidar: SICK's `sick_scan_xd` ROS 2 driver supports the TiM5xx family over Ethernet; the
  TiM561 ships at 192.168.0.1. The Jetson's lidar port is set to 192.168.0.100/24.
- Camera: LUCID's Arena SDK and `arena_camera_ros2`. The camera port runs link-local with jumbo
  frames (MTU 9000).
- IMU: now from the ESC (`vesc_driver` IMU topic) instead of the OAK-D.
- Battery: atlas-battery.service reads the INA228 and keeps a state-of-charge estimate;
  the `atlas_power` ROS 2 node publishes it as `/battery`, with `/estop_ok` and `/charging`.
- Power button: logind shuts the OS down on the power-key event; the drive board then cuts power.
- Charger: the TPS25751 EEPROM image, made once with TI's Application Customization Tool and
  written from the Jetson (`atlas pd flash`).

## Safety

- The BMS works without firmware and sits between the cells and everything else. The main
  switch adds a second, faster short-circuit cut. The E-STOP loop cuts gate drive in hardware.
- There is no fuse between the cells and the BMS FETs, so the pack wiring itself is only as
  safe as its insulation: fish paper on every positive cap, Kapton over every strip, lid on.
- Carbon-fibre-filled filament can conduct at the surface. Never let it be the only
  insulation between two conductors.
- Build and first-charge the pack with an adult supervising, on a non-flammable surface.
- Check the ESC's temperature at 50 A and then 70 A on the bench before racing.

## Why there is no FPGA

The measured bottleneck on car 1 is CPU load (81-90 % on every core with the full stack).
The Jetson's GPU can take the heavy CPU work (the particle filter's ray casting already has a
CUDA implementation), and the STM32 already runs the real-time motor, servo and IMU loops. A
custom RISC-V FPGA would add power, cost and months of design for work the GPU does better.
If a real accelerator need appears later, an off-the-shelf FPGA card (LiteFury or Acorn,
Artix-7 on M.2, which can run open-source RISC-V cores) fits the M.2 slot with no board
change.

## Status and next steps

**Done, 27 September 2026.**

- Drive board: 408 footprints on 6 layers, routed with Freerouting, then
  `boards/tools/mazeroute.py`, with the power copper drawn by hand in `layout.py`. DRC: no
  unconnected nets, no clearance errors. It still warns about silkscreen clipped by the board edge
  (6), one reference over copper, and one 0.2 mm piece of track at a corner of a USB pair that it
  calls open (the piece overlaps the rest of the track).
- Brain board: DRC shows no unconnected nets and no clearance errors. It still lists 199
  footprint-library differences (Antmicro's footprints are not the stock KiCad ones), 37
  silkscreen warnings, and the courtyard and hole overlaps that Antmicro excluded in their project.
- Fabrication files for both boards are in `boards/*/out/fab/`: zipped Gerbers and drill files,
  pick-and-place and BOM.
- The stack header check passes: 40 pins on both boards, the corner holes line up, 20 mm gap.
- Simulations: `sim/README.md`. Printed kit: `mech/README.md`.

**Layout notes.** Choices made while routing that the schematic does not show:

- Drive: phase B's outer low-side gate resistor R517 sits 0.55 mm closer to its gate via than
  the matching resistors of phases A and C, so the driver's phase C gate pair can fan out past it.
- Drive: phase A's divider resistor R507 and filter capacitor C508 are on the underside, beside
  SENS_A's via under the corner of the MCU. On top, the automatic placer had boxed them in.
- Drive: the PPHV branch to C713 runs straight down beside it. That lets the charger's STAT line
  leave the CHG_PMID copper to the west instead of cutting that pour in two.
- Drive: PD_IRQ_N runs along the edge of the motor-supply keep-out, which leaves room beside U701
  for the two vias that take the stack's I2C lines down to the inner layers.
- Drive: about 20 capacitors and resistors had their ground pad cut off in a small island of the
  outer ground fill. Each now has its own via or a short track to ground. Five of those vias sit
  in or at the pad, which is fine because JLCPCB fills and caps every via on 6-layer boards at no
  charge; keep that option when ordering. To make room, VBUS_C's inner-layer run under C703 moved
  1.5 mm, and short stretches of seven signal and 3.3 V nets were routed again.
- Drive: the stack header's ground pins have one thermal spoke on the inner ground fills. A rule in
  `atlas_drive.kicad_dru` allows that; the planes and outer fills connect them as well.
- Brain: the LM5155's VCC capacitor C1209 sits right under the VCC pin, in the corner the
  inductor, the FET and the controller leave.

**Before ordering.**

1. Measure the chassis numbers in `docs/MEASURE_FIRST.md`, then print the fit coupons and try
   them on the car.
2. Check the USB pair widths in JLCPCB's impedance calculator for the stack-up you order, and
   ask for impedance control on both boards.
3. Order the drive board with its vias filled and capped (JLCPCB's default on 6 layers).
4. Make the TPS25751D's EEPROM files with TI's Application Customization Tool
   (`docs/TPS25751_CONFIG.md`). They are written on the assembled board from the Jetson
   (`docs/FLASHING.md`), so J702 does not need fitting.
5. The POWER_EN fix is in (Sept 29, `docs/FLASHING.md`): R609 to +3V3 instead of GND, plus R625,
   a 10k pull-down on GATE_EN_MCU. It keeps the Jetson powered while the STM32 resets and lets the
   Jetson flash the STM32 itself.

**First power-up.** Pack and BMS alone first, then the main switch and precharge with no motor,
then USB-C charging, then the ESC on the bench at 50 A and 70 A with a thermocouple on a bus
capacitor and on the FETs (see Safety above).

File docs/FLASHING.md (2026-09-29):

# Programming the car v2 boards

Every chip is programmed on the assembled boards, never before it is soldered. This page is
the order to do it in and the commands. None of it has been tried on real boards yet: the
boards are not built. Where a step is untested or depends on a guess, it says so.

## What gets programmed

| Part | What | First time | Later |
| --- | --- | --- | --- |
| STM32F405 (drive U601) | VESC 6.06 with the ATLAS_DRV1 target + VESC bootloader | SWD on J601 with an ST-Link (step 1) | VESC Tool over USB (step 7) |
| Jetson Orin Nano module + NVMe | JetPack for the Orin Nano Super | On the NVIDIA dev kit carrier (step 3) | `apt` updates; reflash the same way |
| TPS25751D (drive U701) | PD sink and charger settings in its EEPROM (U702) | From the Jetson through the controller (step 6) | `atlas pd update` |
| 24AA02 (drive U1002) | Board ID record | `atlas id --write` (step 8) | same |

Nothing to program: BQ25798 (the PD controller sets it up), USB2514B (strapped), CP2102N
(factory default), TPS23861 (auto mode), BQ7791508 (fixed thresholds), INA228 (set up at run
time), LAN7800.

## Tools

- An ST-Link with a 10-pin 1.27 mm Cortex debug cable for J601. An STLINK-V3SET is on the
  Syslab purchase sheet (row 96); its box includes a flat cable from its 14-pin STDC14
  connector to that 10-pin header.
- A PC with one of: OpenOCD, stlink-tools (`st-flash`), or STM32CubeProgrammer. The team
  laptop (CachyOS) has none of them; `sudo pacman -S openocd stlink` installs the first two.
- VESC Tool 6.06 (on the laptop at ~/vesc_tool/build/lin/vesc_tool_6.06).
- An Ubuntu PC or VM for NVIDIA's flashing tools (SDK Manager or the L4T flash scripts).
- The NVIDIA Orin Nano Super developer kit (on the order) for the first Jetson flash.
- Optional: an Adafruit FT232H (purchase sheet row 95) to set up USB-C charging before the
  brain board is on the car (step 6, bench variant).

Firmware files: `firmware/vesc/prebuilt/` (built from this repo, see `BUILD_INFO.txt` there),
or build them with `firmware/vesc/build.sh`.

## 1. STM32 first flash (drive board, SWD)

Do it before the brain board goes on: J601 is at drive (105.5, 33.5), under the brain board
once stacked, and whether a debug cable fits through the 20 mm gap has not been checked.

1. Pack connected (or a current-limited bench supply on the pack terminals, 14-16 V, 0.5 A).
   Press the power button: the latch turns on the 5 V and 3.3 V rails, and a blank STM32
   cannot turn them off again (KILL has a pull-down).
2. ST-Link on J601 (pin 1 marked on the silkscreen). J601 carries 3.3 V as the reference only.
3. Write the combined image (firmware at 0x08000000, VESC bootloader at 0x080E0000):

   ```
   openocd -f interface/stlink.cfg -f target/stm32f4x.cfg \
     -c "program firmware/vesc/prebuilt/atlas_drv1_full.hex verify reset exit"
   ```
   or `st-flash --reset --format ihex write firmware/vesc/prebuilt/atlas_drv1_full.hex`,
   or `STM32_Programmer_CLI -c port=SWD -w firmware/vesc/prebuilt/atlas_drv1_full.hex -v -rst`.

   Use the .hex, not the .bin: the bootloader is only in the .hex, and VESC Tool needs it for
   every later update.
4. USB-C cable to the laptop, FLASH switch (SW801) on normal. The STM32 is on hub port 2.
   Open VESC Tool, connect: it should report firmware 6.06, hardware ATLAS_DRV1. In its
   terminal, `atlas_status` prints the main switch, E-stop, gate driver and brain board state.
5. Motor and current set-up: docs/COMPLETE_CAR.md.

## 2. Stack the boards

Brain board on the drive board (mech/README.md). With the car on, the STM32 raises POWER_EN
and the brain board powers up; about 5 s later the STM32 presses the Jetson's power button
if the Jetson has not started by itself.

**SW1 on the brain board** (slide switch, near the rear edge) must be in button mode, with
its pins 2 and 3 connected (check with a meter; which slider position that is has not been
checked). In the other position Antmicro's auto-on circuit restarts the Jetson a few seconds
after every shutdown, and the drive board would never see it stay halted.

## 3. Jetson module and NVMe

Flash on the NVIDIA dev kit first. It is NVIDIA's supported path, and the brain board
carries the same module ports the software uses:

1. Module and NVMe on the dev kit carrier. Flash JetPack with SDK Manager or the L4T scripts,
   following NVIDIA's instructions for the Orin Nano Super developer kit. The laptop has an
   unchecked image, ~/Downloads/jetpack72/jetsoninstaller-r39.2.1-arm64.iso; check that the
   release supports the Orin Nano before using it.
2. First boot on the dev kit: user `atlas`, network, `sudo apt update && sudo apt upgrade`.
3. Move the module and NVMe to the brain board.

Flashing in the car also looks possible but is untested: FLASH switch to flash (USB-C goes
straight to the Jetson's USB0), hold S1 (FORCE_RECOVERY) and switch the car on or press S4
(power). On the brain board, S1 is on the right-hand edge (car right side) 74 mm from the rear
edge, S4 34 mm from the rear, S2 and S3 are user buttons. The STM32 must already run step 1's
firmware, because it powers the brain board. Risk: the brain board has no VBUS detection on
USB0, which NVIDIA's initrd flash may need.

## 4. Atlas tools on the Jetson

```
git clone https://github.com/AtlasAutoware/carv2.git && cd carv2
sudo software/jetson/system/install.sh
sudo reboot
atlas status
```

`atlas status` should list the drive board, the pack voltage, the PD controller's mode,
E-stop, charger, lidar power and the USB0 role. What the install does: docs/SOFTWARE.md.

## 5. Check the stack buses

```
i2cdetect -y -r 7      # stack I2C: 0x20 PD controller, 0x28 PoE controller (and 0x30, its broadcast
                       # address), 0x40 INA228, 0x50-0x57 ID EEPROM (the 24AA02 answers on all eight)
i2cdetect -y -r 1      # brain board: 0x20 expander (and the module's own 0x40)
```
The bus numbers are the usual ones for these controllers (c250000.i2c and c240000.i2c);
`/dev/atlas_i2c_stack` and `/dev/atlas_i2c_sys` point at the right ones either way.

## 6. USB-C PD controller EEPROM

Until this is done the car does not charge from USB-C (the controller waits in PTCH mode).

1. Make the two files with TI's tool: docs/TPS25751_CONFIG.md. Commit them to
   `firmware/tps25751/`.
2. On the Jetson:
   ```
   sudo cp firmware/tps25751/tps25751_lowregion.bin /etc/atlas/
   sudo atlas pd flash firmware/tps25751/tps25751_full.bin --lowregion /etc/atlas/tps25751_lowregion.bin
   atlas pd status
   ```
   `atlas pd flash` loads the configuration into the controller's RAM first (it cannot write
   its EEPROM before it runs one), writes the Full Flash image through the controller (TI's
   FLad/FLwd commands; the controller is the only I2C controller on its EEPROM bus), reads it
   back, checks it with FLvy, writes the region pointer last and restarts the controller from
   the EEPROM. It should end with "the controller booted from the EEPROM".
3. Plug in the 65 W charger. `atlas pd status`: `VBUS PD contract`. `atlas status`: charging.

A power cut in the middle leaves the region pointers cleared, so the controller comes back in
PTCH mode; run the same command again. Meanwhile `/etc/atlas/tps25751_lowregion.bin` keeps
charging working while the car is on (atlas-hw-init loads it at boot).

Later changes: `sudo atlas pd update new_lowregion.bin` (TI's two-region update: the new
bundle goes into the unused region and the pointers switch only after it verifies).

**Bench variant, brain board not on the car:** an FT232H on the drive board's stack socket
reaches the same chips. Wires: D0 (SCL) to socket pin 19, D1 and D2 (SDA, the board's I2C
switch on) to pin 20, GND to pin 36, and D7 to D0 (the PD controller stretches the clock and
pyftdi needs D7 to see it). The drive board has 10k pull-ups on these lines. From the repo on
the laptop:
```
pip install smbus2 pyftdi
cd software/jetson
python3 -m atlas_hw.cli --ftdi pd flash ../../firmware/tps25751/tps25751_full.bin --lowregion ../../firmware/tps25751/tps25751_lowregion.bin
```
J702 (the EEPROM header, not fitted) is not needed for any of this.

## 7. Later STM32 updates (VESC Tool)

VESC Tool, Firmware tab, Custom File: `firmware/vesc/prebuilt/atlas_drv1.bin`, Upload. The
STM32 restarts at the end.

With the POWER_EN fix (below, on every board built from the Sept 29 files) the brain board and
the Jetson stay up through that restart. **On a board without it**, the restart switches the brain
board off without warning. So first: in the VESC Tool terminal `atlas_autooff 0` (the car stays on when the
Jetson halts), then `sudo poweroff` on the Jetson and wait for it to halt, then upload. The
STM32 does not press the Jetson's power button again after a shutdown, so it stays off until
the upload. The new firmware powers the brain board up and, 5 s later, starts the Jetson.

## 8. Board ID

```
sudo atlas id --write --serial 001 --rev A
```

## The POWER_EN fix (applied Sept 29, 2026)

Before this change R609 (100k, drive board) pulled STK_POWER_EN down, so whenever the STM32 was
in reset, flashing, or blank, the brain board and the Jetson lost power. The drive board now has
two resistors for it:

- R609 goes to +3V3 instead of GND. The firmware already drives PA4 high at start-up and low
  before it turns the car off, so only the reset and flashing moments change.
- R625, a new 10k pull-down on GATE_EN_MCU (PB5, input A of the E-stop AND gate U502), next to
  U502. Before it, nothing held that line while the STM32 is in reset or in its ROM bootloader. The bootloader uses PB5 as
  CAN2 RX and may pull it up, and it also uses PA9/PA10 (PWM_BH/PWM_CH), PB13 (PWM_AL) and
  PC10/PC11 (ESTOP_OK, IMU SDA) for its USART1, USART3 and CAN2 interfaces (ST AN2606; the
  exact pin states there have not been checked). With the gate driver held off by the
  pull-down, those pins cannot switch the power stage while the motor bus is still charged.

With both:

- The Jetson stays up through STM32 resets and VESC Tool updates.
- The Jetson can flash the STM32 itself, even a blank one, with no ST-Link and no cable in
  the stack gap: `atlas stm32 bootloader` (expander P1 = BOOT0, P0 = reset) starts the STM32's
  ROM bootloader, which listens on USART3 (PB10/PB11, the Jetson UART) and on USB DFU (hub
  port 2); then `stm32flash -b 115200 -w atlas_drv1_full.hex -v /dev/atlas_vesc` and
  `atlas stm32 run`. Unplug the USB-C cable during a UART flash so the bootloader does not pick
  USB instead. Untested; stm32flash's handling of a .hex with a gap has not been checked.
  Without the GATE_EN pull-down, do not use this route (see above).
- The brain board powers up as soon as the car is on, before the STM32 runs.

`ATLAS_POWER_EN_FIXED=1` in /etc/atlas/atlas.conf (the installed default now) unlocks
`atlas stm32`. Set it to 0 on a board built from files older than Sept 29.

## Troubleshooting

- `atlas pd status` says PTCH: the EEPROM is blank or was not accepted. `sudo atlas pd load
  /etc/atlas/tps25751_lowregion.bin` runs the configuration until the next power cycle.
- VESC Tool does not see the ESC: FLASH switch on normal, USB-C cable with data lines.
- `atlas: cannot open /dev/i2c-7`: log out and in again after install (i2c group).
- The Jetson turns off shortly after boot: the drive board saw it halted for 3 s after it had
  been running. Check SW1 (step 2) and `atlas_status` in VESC Tool.

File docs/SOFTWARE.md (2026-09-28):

# Car v2 software

What runs on the two boards, what it does and where it lives. How to get it onto the boards:
docs/FLASHING.md. Nothing here has run on real boards yet; the firmware compiles and the
Jetson tools pass their tests against simulated chips (`software/jetson/tests`).

## STM32 on the drive board: VESC 6.06 with the ATLAS_DRV1 target

`firmware/vesc/hw_atlas_drv1.c` and `.h`, a VESC hardware target based on the HD60 one
(same STM32F405 + DRV8323RS family). `firmware/vesc/build.sh` clones the VESC sources at the
6.06 release (the version of VESC Tool on the team laptop), adds the target and builds; the
results go to `firmware/vesc/out/`. `firmware/vesc/prebuilt/` holds a build of the committed
sources with its `BUILD_INFO.txt`. Building needs `arm-none-eabi-gcc` (on CachyOS:
`sudo pacman -S arm-none-eabi-gcc arm-none-eabi-newlib`); the script tries VESC's own
GCC 7 download first and falls back to the system compiler.

Differences from a stock VESC, all in the target files:

- **Pins.** Gate driver SPI, current sensing (40 V/V), hall and servo inputs, USART3 to the
  Jetson at 115200, the IMU on I2C, plus the Atlas I/O: KILL (PB12), MAIN_ON (PA6), PRECHG_ON
  (PA7), brain board POWER_EN (PA4), Jetson power key (PC14), OS_HALTED, E-stop, the TPS48111
  current monitor (PA5, 46 V/V over 0.2 mOhm).
- **Main switch and precharge.** At start-up the STM32 closes the precharge path, checks that
  the motor bus rises (below 4 V after 10 ms means a short: stop) and settles above 9 V
  within 400 ms, then turns on the main FETs. A failed precharge is not retried by itself;
  `atlas_precharge` in the VESC Tool terminal retries it (at most every 15 s, for the
  precharge resistors). If the bus collapses while on (a TPS48111 over-current trip), the
  STM32 drops MAIN_ON so the chip's own 15 s retry cannot close the FETs onto an empty bus,
  and precharges again 15 s later, three times at most.
- **E-stop and gate driver.** While the loop is open the motor ignores commands. The DRV8323RS
  runs from the switched bus and forgets its settings whenever ENABLE drops for about a
  millisecond, so the firmware writes the 40 V/V gain and the over-current settings back
  after every precharge and E-stop release, reads the gain back every 5 ms, and holds the
  motor for 0.5 s after a restore. VESC measures the current-sensor offsets once at boot; if
  the gate driver was not configured the whole time, the firmware measures them again (about
  1.4 s, commands locked out) once the E-stop is closed and the motor is still.
- **Jetson.** 5 s after the brain board gets power, if the Jetson has not started by itself,
  the STM32 presses its power button (up to twice, 20 s apart). It never presses after the
  Jetson has run, so a Jetson shut down on purpose stays down. Once the Jetson has run, a halt
  lasting 3 s makes the STM32 switch the car off (`atlas_autooff 0` turns that off until the
  next start).
- **Power button.** A press (30 ms, so a spike on the remote button lead does not count) asks
  the Jetson to shut down (1 s on the power-key line, again every 10 s in case it was still
  booting), waits up to 60 s for it to halt, then switches off the brain board, the main switch
  and the latch.
- **Defaults** for this car (VESC Tool can change them): motor 70 A / -40 A, battery 90 A /
  -12 A, absolute 150 A (the current sensing is linear to about 175 A), battery cut-off
  13.4-12.6 V (3.35-3.15 V per cell under load, above the BMS cut at 3.00 V; starting values
  to check on the bench), 4 cells, 8.4 Ah, power button mode "toggle button only". The UART
  app is VESC's default (UART at 115200).
- **Terminal commands** (VESC Tool): `atlas_status`, `atlas_precharge`, `atlas_main_off`,
  `atlas_brain on|off|press`, `atlas_autooff 0|1`, `atlas_poweroff`, `test_button`.

## Jetson on the brain board

JetPack for the Orin Nano Super, flashed as for the NVIDIA developer kit, plus
`software/jetson/`, installed by `sudo software/jetson/system/install.sh`:

| Piece | What it does |
| --- | --- |
| `atlas` command (`atlas_hw` package, in /opt/atlas) | `atlas status`, `battery`, `lidar on/off`, `pd ...` (USB-C PD controller), `id` (board ID EEPROM), `usb-role`, `stm32 ...` (needs the POWER_EN fix). `atlas --help` lists everything. |
| atlas-hw-init.service | At boot: sets up the brain board expander (outputs low before they become outputs, so the STM32 is never reset by accident), lidar power as configured, loads the PD configuration into RAM if the PD EEPROM is blank, sets the Jetson's USB0 to device mode. |
| atlas-battery.service | Owns the INA228: pack voltage, current, charge counter and a state-of-charge estimate, written to /run/atlas/battery.json every 2 s. Shuts the Jetson down cleanly if the corrected cell voltage stays under 3.30 V for 30 s. |
| /etc/systemd/logind.conf.d/90-atlas-power-key.conf | The drive board's power button arrives as KEY_POWER: shut down. |
| NetworkManager: atlas-lidar | LAN7800 port (driver lan78xx): 192.168.0.100/24. The TiM561 ships at 192.168.0.1. |
| NetworkManager: atlas-camera | The module's own Ethernet on the camera jack (Realtek, r8168/r8169): link-local, MTU 9000 for GigE Vision. |
| /etc/udev/rules.d/99-atlas.rules | /dev/atlas_vesc (UART to the STM32), /dev/atlas_i2c_stack, /dev/atlas_i2c_sys, group permissions. |
| /etc/atlas/atlas.conf | Lidar at boot, PD Low Region file, low-battery threshold, pack resistance, POWER_EN fix flag. |

Where the parts sit on the Jetson (from the brain board netlist and NVIDIA's pin tables):
stack I2C = module I2C1 = i2c@c250000 (normally /dev/i2c-7): INA228 0x40, ID EEPROM 0x50
(answers 0x50-0x57), PD controller 0x20, PoE controller 0x28 (and its broadcast address 0x30). Brain board I2C = module I2C0 = i2c@c240000
(/dev/i2c-1): expander 0x20. VESC UART = module UART1 = serial@3100000. The tools find the
bus numbers by controller address, so a different numbering does not break them.

### Battery estimate: what to measure

The start-up estimate reads the pack voltage through a generic NMC rest-voltage table and
corrects it with an assumed pack resistance of 0.05 Ohm. Neither is Molicel P28A data. To
calibrate:
- Pack resistance: note `atlas battery` at rest and again under a steady load (lidar on,
  Jetson busy); (V_rest - V_load) / (I_load - I_rest). Put it in ATLAS_PACK_R.
- Rest-voltage table: after a full charge, log `atlas battery --json` during a slow discharge
  with pauses; write the pairs as [[cell_volts, fraction], ...] to /etc/atlas/ocv.json.
After that, coulomb counting keeps the percentage. The INA228 only counts while the car is on,
so a charge with the car off is picked up from the voltage at the next start-up.

## ROS 2

`software/ros2/atlas_power` (ament_python; copy or link it into the car's workspace):

- `/battery` (sensor_msgs/BatteryState, from atlas-battery.service), `/estop_ok` and
  `/charging` (std_msgs/Bool), service `/lidar_power` (std_srvs/SetBool).
- `ros2 launch atlas_power atlas_power.launch.py`

Changes to car 1's stack for car 2:
- `vesc_driver`: `port: /dev/atlas_vesc` (115200, as on car 1).
- Lidar: `sick_scan_xd`, TiM5xx launch file, `hostname: 192.168.0.1`.
- Camera: LUCID's Arena SDK and `arena_camera_ros2`; set the camera's packet size to use the
  9000-byte MTU.
- IMU: the drive board's LSM6DS3 through the VESC (if the `vesc_driver` version in use
  publishes it) instead of the OAK-D.

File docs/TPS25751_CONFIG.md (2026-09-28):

# TPS25751D configuration (USB-C PD sink + BQ25798 charger)

The drive board's PD controller (U701, TPS25751DREFR) does nothing useful until it has a
configuration: its ADCIN pins select SafeMode (ADCIN1 = LDO_3V3, ADCIN2 = GND), so the sink path
stays off and USB PD stays disabled until one loads (TI SLVSH93A, section 8.4.1). The
configuration also tells it how to program the BQ25798 charger (U703, 0x6B on the controller's
own I2C bus). It lives in the M24512 EEPROM (U702, 0x50 on that bus).

This page lists what to enter in TI's **TPS25751 Application Customization Tool** (a web tool
on dev.ti.com, TI account needed) and which files to export. The tool's exact screens are not
described here because nobody on the team has used it yet; the values below come from the
board design (`boards/drive/design.py`, block G_CHARGE) and the pack.

## Files to export

- **Full Flash binary**: the whole EEPROM image, region headers included. Written once per
  board: `atlas pd flash` (docs/FLASHING.md, step 6). TI's EEPROM application note (SLVAFL1):
  "The external EEPROM shall be programmed with a Full Flash binary the very first time".
- **Low Region binary**: the configuration bundle alone. Used to run the configuration from RAM
  while the EEPROM is blank (`atlas pd load`, and at every boot through `atlas pd ensure`) and
  for later updates (`atlas pd update`).

Export both from the same session, name them `tps25751_full.bin` and
`tps25751_lowregion.bin`, and commit them to `firmware/tps25751/` with a note of the tool
version. `atlas pd flash` checks that the Low Region binary sits inside the Full Flash image
where TI's layout puts it, which catches files from different sessions.

## Settings

| Setting | Value | Why |
| --- | --- | --- |
| Port role | Sink only | The board never sources (design.py, the PP5V capacitor: "sink-only board: never sourced"). |
| USB data | None through the PD controller | D+/D- go straight to the USB2514B hub; the controller only handles power. |
| Sink PDOs | 5 V 3 A, 9 V 3 A, 15 V 3 A, 20 V 3.25 A | 20 V is the highest the board takes: SMF24A TVS (24 V standoff) and 25 V capacitors on VBUS. No PPS, no EPR. 3.25 A matches the Anker 715 (A2663, 65 W) on the parts list. |
| Battery charger | BQ25798 (listed as supported on page 1 of SLVSH93A) | I2C address 0x6B on the controller's I2C bus. |
| Cells in series | 4 | 4S3P Molicel P28A. The PROG resistor (17.4k) already sets 4S at power-up. |
| Charge voltage | **16.4 V** (4.10 V per cell). Judgment call, see below | The BMS (BQ7791508) cuts at 4.20 V per cell. Charging to 16.8 V leaves no margin for cell imbalance, and the BMS would cut the charge at the end. |
| Charge current | **3.75 A** (1.25 A per cell). Judgment call | docs/ARCHITECTURE.md plans about 60 W into the pack with the car off (about 2.5 h from empty). BQ25798 allows up to 5 A. |
| Input current limit | 3.25 A | Same as the ILIM_HIZ resistors (39k / 100k). A lower value from the PD contract wins automatically. |
| Precharge / termination | Tool defaults | |
| Battery temperature (TS) | Ignore / fixed | TS sees a fixed 25 C divider; the pack NTC goes to the BMS. |
| GPIO0-GPIO7 | **Unused, never outputs** | All eight are tied to GND on the board. A GPIO configured as a driven-high output would short. GPIO11 is not connected. |
| I2C target interrupt | Not needed | PD_IRQ_N has a pull-up but goes nowhere. The Jetson polls. |
| Liquid detection, BC1.2, source features | Off | Not on this board. |

**Charge voltage.** 16.4 V gives up some capacity (for Li-ion cells, stopping at 4.10 V instead
of 4.20 V typically costs around 10 %; not measured on the P28A). 16.6 V (4.15 V per cell)
is the highest value that still leaves some margin under the BMS trip. Ragini or Eshan decide;
16.4 V is the safer starting point.

**Charge current.** 3.75 A is the design figure; the P28A's own charge limits are in Molicel's
data sheet and must be checked before raising it.

## After programming

`atlas pd status` should show mode `'APP '` and "EEPROM found". With the Anker charger plugged
in: `VBUS PD contract`, and `atlas battery` shows a negative current (the pack charging) when
the car's own load is below what the charger delivers.

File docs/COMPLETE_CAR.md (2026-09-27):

# What it takes to finish the car

By 27 September the two boards, the pack and the printed kit were done, but a few things a builder needs were
not drawn yet. Later that day the whole car was put together in one model: the kit and boards, every mating
plug and every cable run, plus a stand-in Slash 4x4 underneath. `mech/extras.py` checks all of it against the kit
the same way `mech/kit.py` checks the kit itself.

That turned up two parts that could not have been assembled as drawn. It also showed what was still missing: a
cover over the board stack with somewhere to mount the Wi-Fi antennas, a stand for the bench tests, and a few
small bought parts.

## Fixed in the kit (`mech/kit.py`)

**The camera plug had nowhere to go.** The camera's RJ45 jack (brain board J6, from Antmicro's layout) opens
toward the car's right side, 2 mm from the right side pod's inner wall. The side-pod fan sat directly outboard
of it, at x -46 to -6. A plug and its boot need about 32 mm straight out of the jack.

- The fan moved forward to x -16 to 24 (`FAN_X`). It is now centred on the ESC power stage (x -30 to 20)
  instead of behind it. The 32 mm screw pattern moved with it.
- The right pod has a 20 mm slot, open at the top, through both walls at the jack (`CAM_PLUG_NOTCH`, x -40.5 to
  -20.5, from z 27 up). The plug and boot pass through it with 3 mm to spare on each side and 4.7 mm above the
  slot floor.
- Two pairs of zip-tie slots on the right pod's top (`POD_TIE_SLOTS_X`, x 4 and 70) hold the camera cable.
  From there it runs forward and up to the camera.

**The servo-lead slot was blocked.** The deck slot for the steering servo lead (x 86 to 98) sat over the right
front splice plate (x 67 to 97) and around the joint bolt at (92, -40). That bolt had no deck around it.

- The slot is now 5 x 24 mm at x 98.5 to 103.5 (`SERVO_SLOT`). That is between the splice plates and the cross
  rib at x 104.
- A 3-pin servo plug goes through it on edge.

Both changes rerun clean: `kit.py` reports no interference, and the pack still fits its bay with 2.8 mm under it.

## New parts (`mech/extras.py`)

| part | what it is for | print |
| --- | --- | --- |
| `stack_canopy` | A cover over the board stack. It protects the Jetson and the boards in a roll, gives the Wi-Fi antennas somewhere to mount, and carries a hex grille over the Jetson fan. | PETG-CF, top face down, no supports; 128 x 99 x 6.4 mm, about 41 g solid |
| `bench_stand` | Holds the chassis by its floor with the wheels about 13 mm off the bench. The ESC bench tests at 50 A and 70 A need the wheels free (ARCHITECTURE.md, First power-up). | PLA or PETG, top down; 173 x 123 x 128 mm |

**Canopy details**

- It sits on three M3 x 40 mm male-female standoffs. They screw into the brain board's corner holes in place of
  three of the four M3 x 6 top screws.
- Its underside is at z 70.2, which is 8 mm above the Jetson fan.
- The fourth corner is Antmicro's H4 (brain-local 10, 5). The camera RJ45 sits on top of it, so nothing can go
  into it from above.
- The canopy's lip, standoffs and antennas all sit in the lidar's 90 degree blind sector at the rear. The lidar
  plane check in `out/extras_report.json` shows every one of them at 147 degrees or more from dead ahead.
- **Antennas:** two RP-SMA jacks (6.5 mm hole with a 5.8 mm flat), 60 mm apart at the rear edge.
  - The M.2 Wi-Fi card comes over from the dev kit and sits under the Jetson module. Two pigtails run from it
    to the canopy.
  - The antennas are swivel dipoles, so they can fold back.
- "ATLAS" is engraved 0.6 mm into the top. It prints first, on the bed.

**Bench stand**

- It is a hollow truncated pyramid, 170 x 120 mm at the bench and 150 x 80 mm on top, with a pocket for a 1.5 mm
  foam pad.
- It is 125 mm tall. The chassis floor is about 72 mm off the ground at ride height, so the stand lifts the car
  53 mm. That leaves about 13 mm under the tyres if the suspension drops 40 mm.
- The 40 mm droop is an estimate: measure it (MEASURE_FIRST.md #13).

## Cables

Every cable is modelled as a path through the car. Each path is checked against the kit, the boards, the other
new parts and the chassis keep-outs, and none of them hit anything. `docs/WIRING.md` lists each run, its length
in the model, and the length to cut. The main runs:

- The camera cable comes out of the right pod's slot and runs along the pod's top, then up to the camera.
- Both lidar cables stay under the camera arch, below the scan plane.
- The motor phases and hall lead pass over the drive board's rear edge and under it, then down through the
  existing deck opening to the motor's end bell.
- The servo lead drops through the new slot.
- The pack leads come up through the lid slots and down into the board's through-hole wire pads.

Two cables cross the lidar's scan plane: the camera cable at 142 degrees from dead ahead and one Wi-Fi pigtail
at 180 degrees. Both are inside the blind sector.

## Added to the parts list (`bom/make_bom.py`)

New lines, asked for on 27 September as items 13-16 of the Syslab order (all Amazon):

- two Bingfu dual-band 3 dBi RP-SMA antennas, 12 cm (B082SHKT3Q, $5.39 the pair)
- two Tenmory MHF4 to RP-SMA bulkhead pigtails, 15 cm (B07RXDTC7G, $6.99 the pair)
- M3 x 40 mm male-female brass standoffs for the canopy, pack of 25 (B0CFJNP726, $7.99; 3 used). The three
  M3 x 6 screws come from the hardware assortment.
- JST-PH 2-pin leads, 20 pairs (B0D9R21XYY, $8.99). One of them, with its two wires soldered together, closes the
  E-stop input when no E-stop button is fitted.

Zip ties come from the lab. The new lines add $29.36, and the car's total is now $1,951.15. The phase 1 figure
($1,366.88) leaves out the antennas, pigtails and canopy standoffs, which only go with the brain board.

The canopy adds about 30 g of the PETG-CF already on hand. The bench stand is about 0.2 kg of PLA.

## Still to check on the real parts

- The RJ45 plug and boot sizes in the model are typical: 12 x 8 x 21 mm plug, 14 x 10 x 11 mm boot. A fat boot
  on the camera cable may need the slot widened (`CAM_PLUG_NOTCH`).
- The Wi-Fi card's antenna connectors. The dev kit ships with an AzureWave AW-CB375NF, and its datasheet gives
  I-PEX MHF4 jacks, so the pigtails on the order are MHF4. Check the card when the kit arrives.
- Brain board corner H4: confirm on the real jack that the 20 mm standoff under it needs no screw. The other
  three corners are screwed through the canopy standoffs.
- The chassis stand-in in the renders is drawn from kit.py's keep-out numbers. The suspension, wheels and body
  posts are drawn to look plausible, not measured.

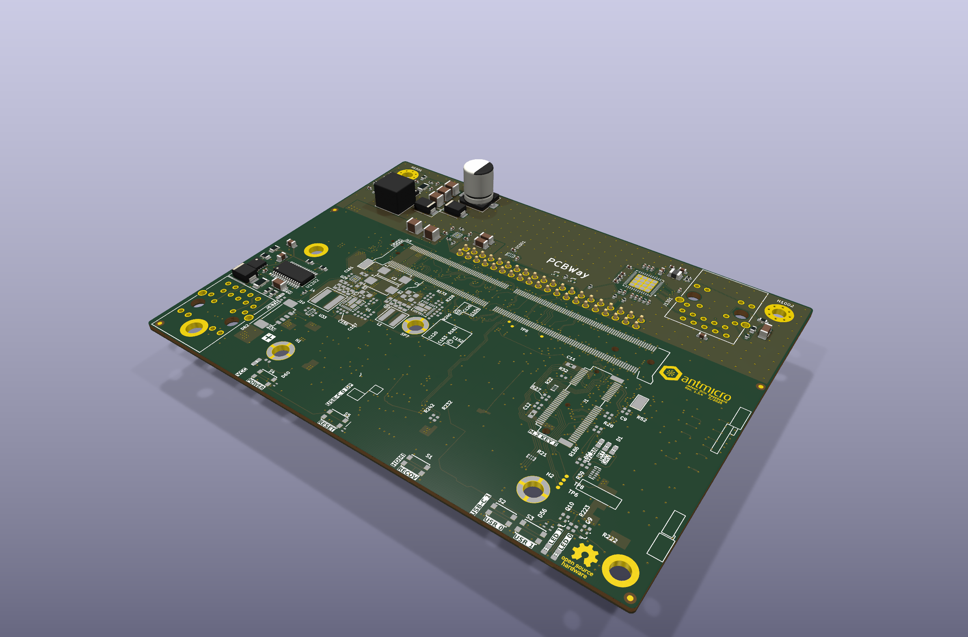
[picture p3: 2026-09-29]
boards/brain/out/render/brain_iso.png

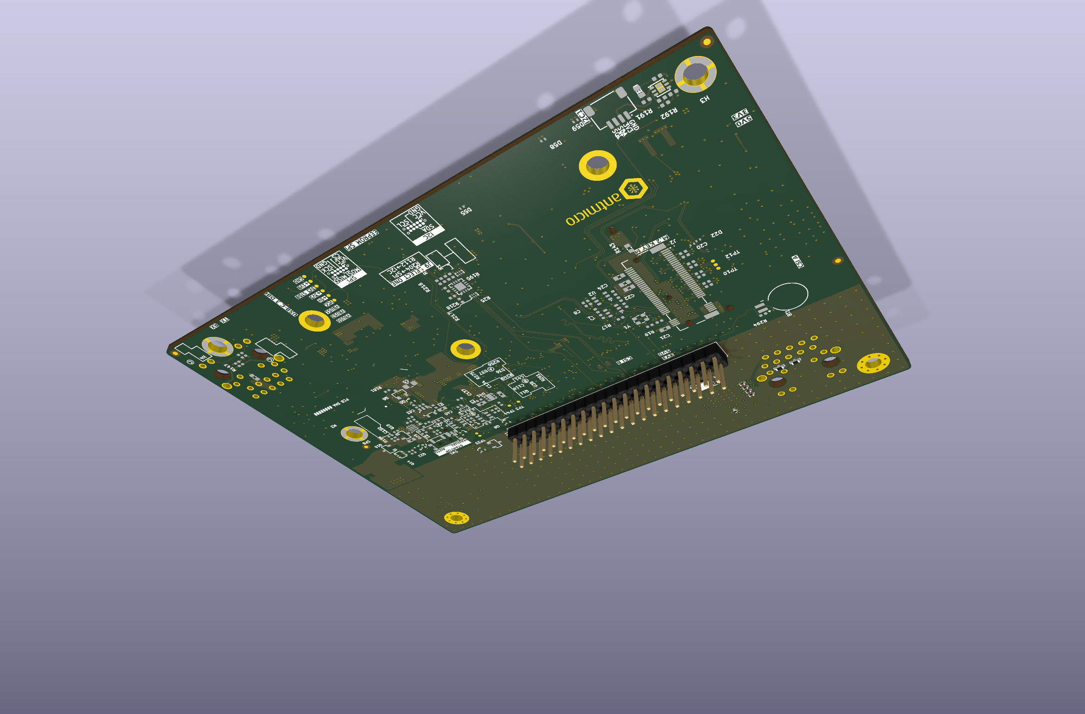
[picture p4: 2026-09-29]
boards/brain/out/render/brain_iso_bottom.png

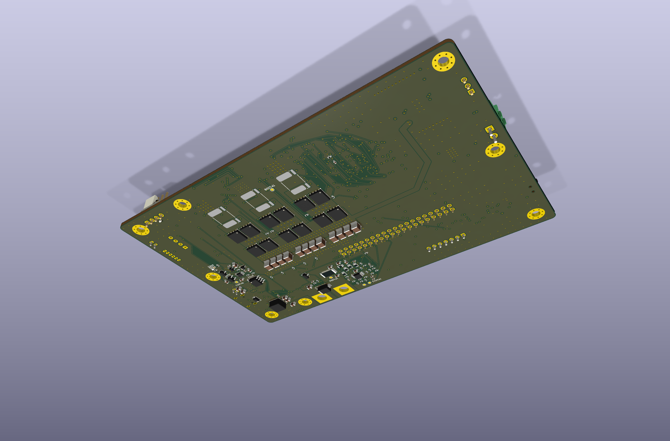
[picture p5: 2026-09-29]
boards/drive/out/render/drive_iso_bottom.png

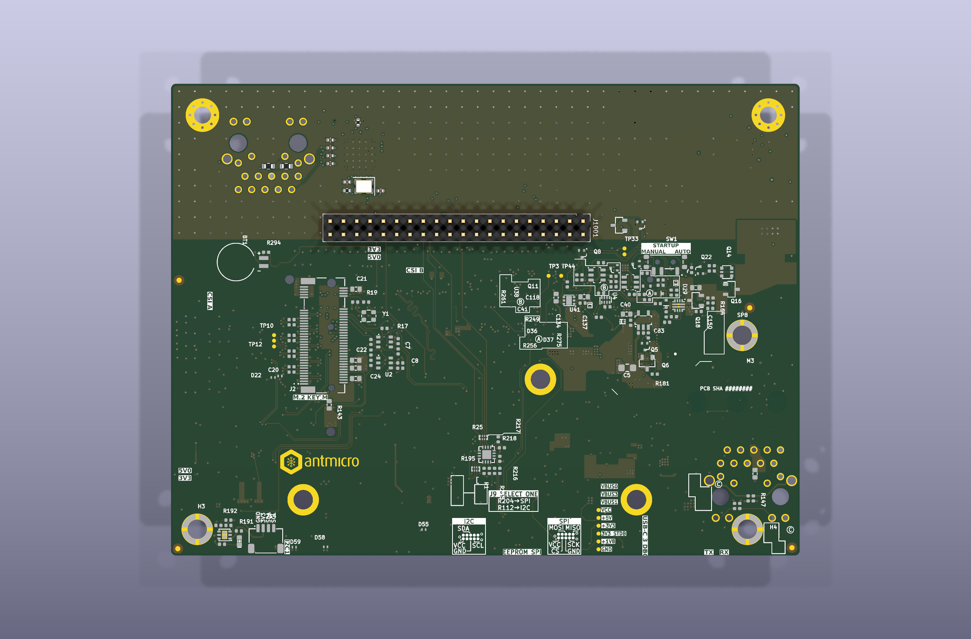
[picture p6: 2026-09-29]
boards/brain/out/render/brain_bottom.png

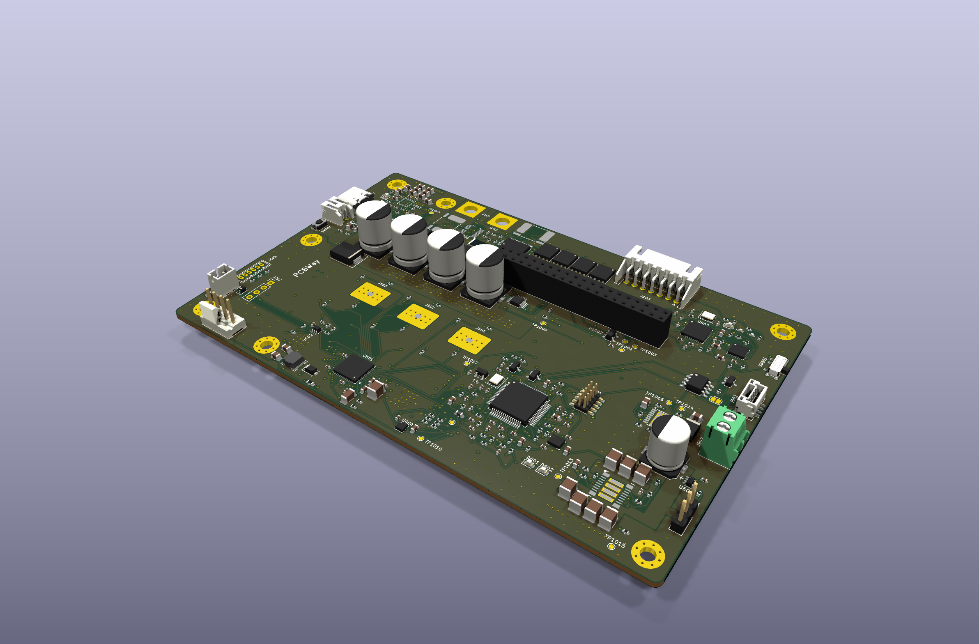
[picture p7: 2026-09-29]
boards/drive/out/render/drive_iso.png

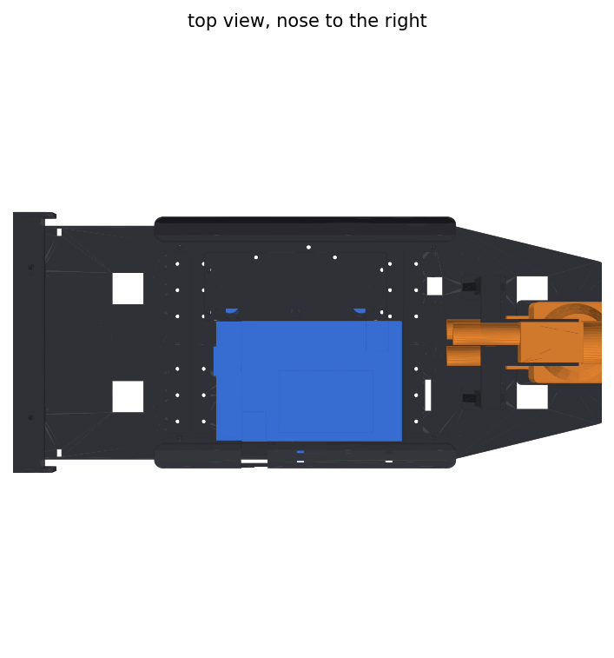
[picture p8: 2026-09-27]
mech/out/renders/kit_top.png

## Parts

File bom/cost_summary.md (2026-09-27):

| line | USD |
| --- | ---: |
| Drive board (parts + fab x5 + assembly x1) | 525.70 |
| Brain board / Jetson carrier (parts + fab x5 + assembly x1) | 563.90 |
| 18650 pack materials (cells, nickel, insulation, leads) | 134.20 |
| Lens | 144.00 |
| Charger, cable, fan, thermal pad, hardware, antennas | 124.35 |
| NEW PURCHASES, total | 1,492.15 |
| Still-needed items already on the sheet (Jetson dev kit, NVMe) | 459.00 |
| CAR V2 TOTAL (new purchases + sheet items) | 1,951.15 |
| Conditional: camera M12 cable (skip if LUCID includes one) | 30.00 |
| Optional: spot welder (only if the lab has none) | 304.51 |
| Worst case (everything above) | 2,285.66 |
| Phase 1 only (drive board + pack + kit, Jetson on its dev-kit carrier) | 1,366.88 |

Removed from the purchase sheet (no longer needed):

- Flipsky FSESC 6.7 PRO ESC ($107.00): replaced by the ESC on the drive board
- UGREEN Nexode 20,000 mAh 130 W power bank: replaced by the built-in 18650 pack and USB-C charger

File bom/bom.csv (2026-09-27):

group | item | part_number | qty | unit_usd | ext_usd | status | price_basis | source | reason
have | Traxxas Slash 4x4 chassis (new car) with Holmes Hobbies Puller Pro 540 2200 kV sensored motor | KA2246-R00 label, 6822 chassis | 1 | 0.00 | 0.00 | have | - | - | The rolling chassis for car 2.
have | INJORA INJS235 35 kg brushless steering servo | INJS235 | 1 | 0.00 | 0.00 | have | - | - | Drops into the Slash 4x4 servo bulkhead; powered by the drive board 7.5 V rail.
have | SICK TiM561 270 degree lidar + donor M12 power and M12-D to RJ45 cables | TiM561-2050101 | 1 | 0.00 | 0.00 | have | - | - | Donated lidar; Ethernet to the brain board, 9-28 V from the drive board eFuse.
have | LUCID Triton 2.3 MP GigE PoE camera | TRI023S-CC | 1 | 0.00 | 0.00 | have | - | - | Donated camera (at school); powered over PoE by the brain board.
have | Carbon-fibre filament for all printed parts (about 0.85 kg with the canopy), PLA for the bench stand (about 0.2 kg) | PETG-CF or PA-CF; PLA | 1 | 0.00 | 0.00 | have | - | - | At school.
have | SendCutSend $250 service credit | - | 1 | 0.00 | 0.00 | have | - | - | Covers the aluminium heat spreader cut.
sheet_keep | NVIDIA Jetson Orin Nano Super Developer Kit | 945-13766-0005-000 | 1 | 399.00 | 399.00 | sheet_keep | quoted | https://marketplace.nvidia.com/en-us/enterprise/robotics-edge/jetson-orin-nano-super-developer-kit/ | The module moves onto the brain board; the dev-kit carrier stays as a known-good fallback for bring-up.
sheet_keep | SanDisk Optimus 5100 500 GB NVMe | SDS...5100 500GB | 1 | 60.00 | 60.00 | sheet_keep | estimate | link on the sheet | Goes in the brain board M.2 Key M slot: OS, TensorRT engines and training logs.
drive_pcb | MCU running VESC firmware | STM32F405RGT6 | 1 | 14.00 | 14.00 | buy | estimate | st.com / digikey | Same MCU as VESC 6, so stock VESC firmware and the ROS vesc_driver keep working (firmware/vesc compiles).
drive_pcb | Gate driver, 3 current-sense amps, 600 mA buck | DRV8323RSRGZR | 1 | 6.50 | 6.50 | buy | estimate | ti.com/product/DRV8323R | Supported by VESC firmware; the buck makes the 5 V logic rail.
drive_pcb | 40 V 0.79 mOhm N-FET, SON 5x6 (ESC 12, main switch 4 + precharge 1, BMS 8) | CSD18510Q5B | 25 | 2.10 | 52.50 | buy | estimate | ti.com/product/CSD18510Q5B | One FET type everywhere; two in parallel per ESC switch.
drive_pcb | Current shunt 0.2 mOhm, 4-terminal (ESC x3, main switch x1) | Isabellenhuette BVR-Z-R0002-1.0 | 4 | 4.00 | 16.00 | buy | estimate | mouser | Kelvin sense pads for the DRV8323 amps and the TPS48111.
drive_pcb | BMS sense shunt 0.5 mOhm, 4-terminal | Isabellenhuette BVR-Z-R0005-1.0 | 1 | 4.00 | 4.00 | buy | estimate | mouser | BQ7791508 overcurrent trips and the INA228 energy meter.
drive_pcb | 4S protector with balancing, no firmware | BQ7791508PWR | 1 | 3.20 | 3.20 | buy | estimate | ti.com/product/BQ77915 | OV 4.20 V, UV 3.0 V, OT 65 C, auto-recovery.
drive_pcb | High-side switch controller with precharge (anti-spark main switch) | TPS48111QDGXRQ1 | 1 | 3.50 | 3.50 | buy | estimate | ti.com/product/TPS4811-Q1 | Turns the motor bus on and off, precharges the ESC caps, fast short-circuit cut.
drive_pcb | USB-C buck-boost charger, 1-4S, 5 A | BQ25798RQMR | 1 | 5.50 | 5.50 | buy | estimate | ti.com/product/BQ25798 | Charges the 4S pack from USB-C and powers VSYS while plugged in.
drive_pcb | USB-C PD controller that configures the charger, no MCU | TPS25751DREFR | 1 | 5.00 | 5.00 | buy | estimate | ti.com/product/TPS25751 | Negotiates 20 V and programs the BQ25798; config in the EEPROM below.
drive_pcb | I2C EEPROM for the TPS25751 configuration | M24512-RMN6TP | 1 | 1.00 | 1.00 | buy | estimate | digikey | TPS25751 loads its patch and settings from 0x50.
drive_pcb | USB-C 16-pin receptacle + ESD array | GCT USB4105-GF-A, TPD4E05U06DQAR | 1 | 1.50 | 1.50 | buy | estimate | digikey | The one port for charging and debugging.
drive_pcb | USB 2.0 4-port hub | USB2514B-I/M2 | 1 | 2.50 | 2.50 | buy | estimate | microchip.com | Laptop sees the Jetson, VESC Tool and the serial console on one cable.
drive_pcb | USB 2.0 switches (flash-mode path straight to the Jetson) | TS3USB30EDGSR | 2 | 1.00 | 2.00 | buy | estimate | ti.com | NVIDIA wants a direct USB link for recovery-mode flashing; slide switch SW801 picks it.
drive_pcb | USB to UART bridge (Jetson serial console) | CP2102N-A02-GQFN24 | 1 | 3.00 | 3.00 | buy | estimate | silabs.com | Boot log and console even with the network down.
drive_pcb | Servo supply module, 36 V in, 8 A (set to 7.5 V) | TPSM63610RDFR | 1 | 9.00 | 9.00 | buy | estimate | ti.com/product/TPSM63610 | Integrated inductor; covers the 35 kg servo stall current.
drive_pcb | eFuse for the lidar supply | TPS26600PWPR | 1 | 3.00 | 3.00 | buy | estimate | ti.com/product/TPS2660 | Current-limited 12-16.8 V to the TiM561; the Jetson can power-cycle it.
drive_pcb | Battery power monitor (V, I, energy) read by the Jetson | INA228AIDGSR | 1 | 4.00 | 4.00 | buy | estimate | ti.com/product/INA228 | Real state of charge in ROS.
drive_pcb | IMU on the VESC I2C bus | LSM6DS3TR-C | 1 | 3.00 | 3.00 | buy | estimate | st.com | VESC firmware lsm6ds3 driver (WHO_AM_I 0x6A).
drive_pcb | CAN transceiver, 3.3 V | SN65HVD230DR | 1 | 1.50 | 1.50 | buy | estimate | ti.com | Spare CAN port for later modules.
drive_pcb | Logic and small regulators: always-on LDO, on/off latch, buffers, 3.3 V LDO, board-ID EEPROM | TPS70933, SN74LVC1G74/1G34/1G08, SN74AHCT1G125, TLV75533P, 24AA02 | 1 | 3.50 | 3.50 | buy | estimate | digikey | Power button latch, E-stop gate, servo level shift.
drive_pcb | Inductors: charger 1 uH, 5 V buck 22 uH | Coilcraft XAL5030-102MEB, Bourns SRN4018-220M | 1 | 2.90 | 2.90 | buy | estimate | coilcraft.com / digikey
drive_pcb | DC-link bulk capacitors 330 uF 35 V hybrid polymer, 10 x 12.8 mm | Panasonic EEH-ZU1V331P | 4 | 1.60 | 6.40 | buy | estimate | digikey | ESC DC link; low ESR at the motor ripple current. 12.8 mm tall so the brain board NVMe clears them (the 470 uF 35 V part is 16.8 mm).
drive_pcb | Power ceramics: 16 x 10 uF 50 V 1210, 4 x 47 uF 16 V 1210, 220 uF 16 V polymer | GRM32ER71H106KA12L, GRM32EC81C476ME15L, 16SVPF220M | 1 | 10.20 | 10.20 | buy | estimate | digikey | ESC switching loop and servo supply.
drive_pcb | TVS, ESD and small diodes | SMBJ20A x2, SMCJ20A, SMF24A, PESD5V0S1BA, NUP2105L, BAT54WS, PMEG6010CEH, MMSZ4684 | 1 | 5.00 | 5.00 | buy | estimate | digikey
drive_pcb | Crystals 8 MHz (MCU) and 24 MHz (hub) | 3225 SMD | 2 | 0.50 | 1.00 | buy | estimate | digikey
drive_pcb | Stack socket 2 x 20, 2.54 mm, 8.5 mm tall | Samtec SSQ-120-03-G-D | 1 | 8.00 | 8.00 | buy | estimate | samtec.com | Receives the brain board header across the 20 mm stack gap.
drive_pcb | Board connectors: JST XH 7p, ZH 6p, GH 4p, PH 2p x2, Phoenix 2-pin, servo and fan headers, 1.27 mm SWD | S7B-XH-A, B6B-ZR, BM04B-GHS-TBT, S2B/B2B-PH-K, 1984617, FTSH-105-01-L-DV-K | 1 | 10.00 | 10.00 | buy | estimate | digikey | Everything that plugs into the board.
drive_pcb | Buttons, switches, LEDs, NTC, small FETs | KMR211NG, PCM12SMTR, 0603 LEDs, NCP15XH103, 2N7002K, MMBT3904 | 1 | 3.00 | 3.00 | buy | estimate | digikey
drive_pcb | Resistors and small capacitors (about 290 parts, 0402-0805) | various | 1 | 15.00 | 15.00 | buy | estimate | lcsc / assembler stock | Lumped.
drive_fab | Drive board fab: 140 x 90 mm, 6 layers, 2 oz copper on every layer, ENIG, qty 5 | ATLAS-DRV-1 | 1 | 170.00 | 170.00 | buy | estimate | jlcpcb.com / pcbway.com | 5 bare boards (1 assembled, 4 spares). Six layers so every signal routes; JLCPCB offers 2 oz outer and inner on multilayer boards.
drive_fab | Drive board assembly, double-sided, qty 1 | ATLAS-DRV-1 PCBA | 1 | 150.00 | 150.00 | buy | estimate | jlcpcb.com / pcbway.com | Setup, stencils and labour.
brain_pcb | 260-pin SO-DIMM socket for the Orin module | TE 2309413 (Antmicro J15) | 1 | 6.00 | 6.00 | buy | estimate | github.com/antmicro/jetson-orin-baseboard | The module plugs straight into the board.
brain_pcb | M.2 Key M + Key E sockets and their SMT standoffs | TE 1-2199230-6, 2199230-6, Wurth 9774025151R x2 | 1 | 6.60 | 6.60 | buy | estimate | digikey | NVMe SSD and Wi-Fi card.
brain_pcb | RJ45 magjacks: camera port (PoE through its centre taps) and lidar port | TE 5-2337992-8 | 2 | 5.00 | 10.00 | buy | estimate | digikey | Same jack as Antmicro J6 for both ports.
brain_pcb | USB to Gigabit Ethernet for the lidar | LAN7800-I/Y9X | 1 | 5.50 | 5.50 | buy | estimate | microchip.com | The Orin Nano has one GbE (camera); Linux lan78xx driver.
brain_pcb | PoE PSE controller, runs in auto mode as shipped | TPS23861PWR | 1 | 7.00 | 7.00 | buy | estimate | ti.com/product/TPS23861 | IEEE 802.3af/at source for the camera, no firmware.
brain_pcb | 52 V boost controller for PoE + 100 V FETs (boost and PSE port) | LM5155DSSR, CSD19538Q3A x2 | 1 | 4.30 | 4.30 | buy | estimate | ti.com | Makes the 52 V the PSE needs from VSYS.
brain_pcb | PoE power parts: 47 uH inductor, 100 V diode, 58 V TVS x2, 100 V ceramics, 22 uF 100 V can, 2 kV 1 nF | XAL7070-473MEC, SS2H10, SMBJ58A, GRM32ER72A225KA35L, EEE-FK2A220P, GRM31BR73D102KW01L | 1 | 9.50 | 9.50 | buy | estimate | coilcraft.com / digikey
brain_pcb | Input eFuses (Atlas stack input and Antmicro module rails) | TPS259474ARPWR | 3 | 1.50 | 4.50 | buy | estimate | ti.com
brain_pcb | Module power as in the Antmicro design: 2 bucks + inductors, LDOs, polymer caps | SIC431AED x2, SRP5030CA, SRP6050CA, NCP730, TPS7A05, T521 100 uF x2 | 1 | 14.00 | 14.00 | buy | estimate | antmicro supply.kicad_sch | Copied from the open design.
brain_pcb | Stack header 2 x 20, 2.54 mm, long posts for the 20 mm gap | Samtec TSW-120-xx-G-D (lead code for ~14 mm below the insulator: confirm on samtec.com) | 1 | 6.00 | 6.00 | buy | estimate | samtec.com | Mates the drive board socket.
brain_pcb | Logic, level shifters, expander, ESD, 32 kHz oscillator, RTC holder, buttons, LEDs, fan and debug connectors | PCAL6408A, NTS0102 x3, 74LVC2G07 x2, TPD1E0B04 x9, ECS-2520MV, MS621FE holder, KMR2 x5 ... | 1 | 18.00 | 18.00 | buy | estimate | antmicro BOM | Housekeeping kept from Antmicro plus the stack interface.
brain_pcb | LAN7800 support: 25 MHz crystal, 3.3 uH, small FETs | ABM8-25.000MHZ-B2-T, LQM2HPN3R3MG0L, PJE138K x10, SSM3J332R x4 | 1 | 3.50 | 3.50 | buy | estimate | digikey
brain_pcb | Resistors and small capacitors (about 190 parts) | various | 1 | 9.00 | 9.00 | buy | estimate | lcsc / assembler stock | Lumped.
brain_fab | Brain board fab: 120 x 90 mm, 8 layers, impedance control, 0.2 mm vias, ENIG, qty 5 | ATLAS-BRN-1 | 1 | 260.00 | 260.00 | buy | estimate | jlcpcb.com / pcbway.com | High-speed carrier (PCIe, USB 3, Gigabit pairs).
brain_fab | Brain board assembly, double-sided, qty 1 | ATLAS-BRN-1 PCBA | 1 | 200.00 | 200.00 | buy | estimate | jlcpcb.com / pcbway.com | SO-DIMM socket and QFNs need machine assembly.
pack | Molicel P28A 18650, 2800 mAh, 35 A (12 + 2 spare) | INR-18650-P28A | 14 | 5.99 | 83.86 | buy | quoted | https://www.18650batterystore.com/products/molicel-p28a | 4S3P = 8.4 Ah, 105 A max; in stock (P30B was sold out at three stores).
pack | Pure nickel strip 0.2 x 8 mm, 20 ft | 8mm x 0.2mm | 1 | 10.34 | 10.34 | buy | quoted | https://liionwholesale.com/products/pure-nickel-strip-roll-0-15mm-0-2mm-thickness-6mm-10mm-widths | Two layers on each series joint.
pack | Fish-paper rings, Kapton tape, 1 mm foam pad | various | 1 | 12.00 | 12.00 | buy | estimate | - | Cell-top insulation; the CF filament is not an insulator to rely on.
pack | Pack sense lead: JST-XH 7p housing + crimps, 24 AWG, 10k NTC | various | 1 | 10.00 | 10.00 | buy | estimate | - | Cell taps and pack temperature to the BMS.
pack | 10 AWG + 12 AWG silicone wire, 4 mm bullets | various | 1 | 18.00 | 18.00 | buy | estimate | - | Pack leads and motor-phase pigtails (skip if already in the kit box).
pack_tool | Capacitor spot welder, 100-240 V | Glitter 801D | 1 | 304.51 | 304.51 | optional | quoted ($269.51 + $35 ship) | https://www.ebay.com/itm/186415585726 | Only if the lab has no spot welder; needed to build the pack.
sensor | Lens for the Triton: 3.5 mm C-mount, 1/2 in format (~87 x 61 degrees on the IMX392) | Kowa LM4NCL | 1 | 144.00 | 144.00 | buy | quoted (sale; $198 regular) | https://machinevisiondirect.com/products/kowa-lm4ncl | The camera has no lens; wide view for racing.
sensor | M12 X-coded 8-pin to RJ45 Cat6a, 2 m | LUCID M12-RJ45 2.0 m | 1 | 30.00 | 30.00 | conditional | quoted | https://thinklucid.com/product/m12-to-rj45-ip67-cat6a-cable-2m-dark-green/ | Camera to the PoE port; skip if LUCID ships one with the camera.
charge | USB-C charger 65 W (20 V 3.25 A PDO) | Anker 715 (A2663) | 1 | 29.99 | 29.99 | buy | quoted | https://www.anker.com/products/a2663 | The charger input tops out at 3.3 A, so 65 W is the useful maximum.
charge | USB-C to USB-C cable, 5 A e-marked, 1 m | any 100 W cable | 1 | 10.00 | 10.00 | buy | estimate | - | A 3 A cable would cap charging at 60 W.
cooling | 40 x 10 mm 5 V PWM fan | Noctua NF-A4x10 5V PWM | 1 | 15.00 | 15.00 | buy | estimate | https://www.noctua.at/en/products/nf-a4x10-5v-pwm | Blows across the ESC heat spreader and under the brain board.
cooling | Thermal pad 1.0 mm, 100 x 100 | Arctic TP-3 | 1 | 10.00 | 10.00 | buy | estimate | - | FETs to heat spreader.
cooling | Aluminium heat spreader 3/16 in (4.76 mm) 6061, 60 x 48 mm, 4 holes tapped M3 | SendCutSend, mech/out/dxf/heat_spreader.dxf | 1 | 12.00 | 12.00 | credit | estimate | sendcutsend.com | Covered by the existing SendCutSend credit. 3/16 in leaves 1 mm for the thermal pad under the FETs.
hardware | M3 hardware: 50 brass heat-set inserts, socket-screw assortment, nylocs, MS621FE RTC cell | various | 1 | 22.00 | 22.00 | buy | estimate | - | Deck and sensor mounts (about 45 inserts).
hardware | Board stack standoffs: 6 x M3 7 mm M-F (deck to drive board), 4 x M3 20 mm M-F (drive to brain board) | hex, brass | 1 | 8.00 | 8.00 | buy | estimate | - | The brain board sits on all four corners: two posts thread into deck standoffs through the drive board, two are held by nuts under it.
finish_brain | Wi-Fi antennas: Bingfu dual-band 3 dBi RP-SMA male swivel dipoles, 12 cm, 2-pack | Amazon B082SHKT3Q | 1 | 5.39 | 5.39 | buy | quoted | https://www.amazon.com/dp/B082SHKT3Q | Screw onto the two RP-SMA jacks in the stack canopy. The M.2 Wi-Fi card itself moves over from the dev kit.
finish_brain | Antenna pigtails: Tenmory MHF4 to RP-SMA female bulkhead, 15 cm, 2-pack | Amazon B07RXDTC7G | 1 | 6.99 | 6.99 | buy | quoted | https://www.amazon.com/dp/B07RXDTC7G | The dev kit's Wi-Fi card (AzureWave AW-CB375NF) has MHF4 jacks. Card to canopy; the routed runs are 67 and 80 mm (docs/WIRING.md).
finish_brain | Canopy standoffs: M3 x 40 mm + 6 mm male-female brass hex, pack of 25 (3 used); the M3 x 6 screws come from the hardware assortment | Amazon B0CFJNP726 | 1 | 7.99 | 7.99 | buy | quoted | https://www.amazon.com/dp/B0CFJNP726 | The standoffs replace three of the brain board top screws; the fourth corner (Antmicro H4) is under the camera RJ45.
finish | E-stop loop: JST-PH 2-pin leads, 20 pairs (1 used, its two wires soldered together) | Amazon B0D9R21XYY | 1 | 8.99 | 8.99 | buy | quoted | https://www.amazon.com/dp/B0D9R21XYY | J504 has to be closed for the motor to run when no E-stop button is fitted (ARCHITECTURE.md, What you plug in).
finish | Zip ties 2.5 mm | nylon | 1 | 0.00 | 0.00 | have | - | - | From the lab. Camera cable in the slots on the right side pod, lidar cables on the camera arch, pack and motor leads.

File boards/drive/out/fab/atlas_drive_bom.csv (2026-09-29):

Designator | Value | Footprint | MPN | Manufacturer | Qty
C201-C204 | 1u 16V | Capacitor_SMD:C_0603_1608Metric |  |  | 4
C205,C503,C905 | 1u 25V | Capacitor_SMD:C_0603_1608Metric |  |  | 3
C206,C505 | 1u 6.3V | Capacitor_SMD:C_0402_1005Metric |  |  | 2
C207,C304,C403,C406,C506,C530-C532,C601-C604,C610,C613,C615,C619,C620,C710,C801-C806,C808,C809,C813,C815,C1001,C1002,C1004 | 100n | Capacitor_SMD:C_0402_1005Metric |  |  | 31
C301 | 680n | Capacitor_SMD:C_0402_1005Metric |  |  | 1
C302 | 2.2u 25V | Capacitor_SMD:C_0805_2012Metric |  |  | 1
C303,C408,C501,C711,C714,C721,C904 | 100n 50V | Capacitor_SMD:C_0402_1005Metric |  |  | 7
C401 | 1u 50V | Capacitor_SMD:C_0603_1608Metric |  |  | 1
C402,C608,C609 | 2.2u | Capacitor_SMD:C_0603_1608Metric |  |  | 3
C404,C508,C514,C520,C529,C607 | 10n | Capacitor_SMD:C_0402_1005Metric |  |  | 6
C405,C412,C606,C614,C812 | 1u | Capacitor_SMD:C_0603_1608Metric |  |  | 5
C407 | 4.7u 50V | Capacitor_SMD:C_1206_3216Metric |  |  | 1
C409 | 100n 16V | Capacitor_SMD:C_0402_1005Metric |  |  | 1
C410,C411 | 22u 10V | Capacitor_SMD:C_0805_2012Metric |  |  | 2
C413,C704,C705,C707 | 10u 10V | Capacitor_SMD:C_0805_2012Metric |  |  | 4
C502,C509-C512,C515-C518,C521-C524,C901-C903 | 10u 50V | Capacitor_SMD:C_1210_3225Metric | GRM32ER71H106KA12L |  | 16
C504 | 47n 50V | Capacitor_SMD:C_0603_1608Metric |  |  | 1
C507,C513,C519,C616-C618 | 1n | Capacitor_SMD:C_0402_1005Metric |  |  | 6
C525-C528 | 330u 35V | Capacitor_SMD:CP_Elec_10x10 | EEH-ZU1V331P | Panasonic | 4
C605,C807,C814 | 4.7u | Capacitor_SMD:C_0603_1608Metric |  |  | 3
C611,C612,C810,C811 | 18p | Capacitor_SMD:C_0402_1005Metric |  |  | 4
C701 | 4.7u 25V | Capacitor_SMD:C_0805_2012Metric |  |  | 1
C702,C703 | 390p | Capacitor_SMD:C_0402_1005Metric |  |  | 2
C706,C718 | 4.7u 10V | Capacitor_SMD:C_0603_1608Metric |  |  | 2
C708,C709 | 22u 25V | Capacitor_SMD:C_1206_3216Metric |  |  | 2
C712,C713,C715-C717,C722-C728 | 10u 25V | Capacitor_SMD:C_0805_2012Metric |  |  | 12
C719,C720 | 47n 16V | Capacitor_SMD:C_0402_1005Metric |  |  | 2
C906-C909 | 47u 16V | Capacitor_SMD:C_1210_3225Metric | GRM32EC81C476ME15L | Murata | 4
C910 | 220u 16V | Capacitor_SMD:CP_Elec_8x10 | 16SVPF220M | Panasonic | 1
C911,C913 | 1u 50V | Capacitor_SMD:C_0805_2012Metric |  |  | 2
C912 | 22n | Capacitor_SMD:C_0402_1005Metric |  |  | 1
C1003 | 10n 50V | Capacitor_SMD:C_0402_1005Metric |  |  | 1
D101,D901 | SMBJ20A | Diode_SMD:D_SMB | SMBJ20A | Littelfuse | 2
D301,D602 | RED | LED_SMD:LED_0603_1608Metric |  |  | 2
D302 | SMCJ20A | Diode_SMD:D_SMC | SMCJ20A | Littelfuse | 1
D401 | BAT54WS | Diode_SMD:D_SOD-323 | BAT54WS | Nexperia | 1
D402 | PMEG6010CEH | Diode_SMD:D_SOD-123F | PMEG6010CEH | Nexperia | 1
D403,D601 | GREEN | LED_SMD:LED_0603_1608Metric |  |  | 2
D501 | PESD5V0S1BA | Diode_SMD:D_SOD-323 | PESD5V0S1BA | Nexperia | 1
D603 | NUP2105L | Package_TO_SOT_SMD:SOT-23 | NUP2105LT1G | onsemi | 1
D701 | TPD4E05U06 | Package_SON:USON-10_2.5x1.0mm_P0.5mm | TPD4E05U06DQAR | Texas Instruments | 1
D702 | SMF24A | Diode_SMD:D_SOD-123F | SMF24A | Littelfuse | 1
D703 | AMBER | LED_SMD:LED_0603_1608Metric |  |  | 1
D801 | BLUE | LED_SMD:LED_0603_1608Metric |  |  | 1
D802 | MMSZ4684 | Diode_SMD:D_SOD-123 | MMSZ4684T1G | onsemi | 1
D803 | GREEN | LED_SMD:LED_0402_1005Metric |  |  | 1
D804 | YELLOW | LED_SMD:LED_0402_1005Metric |  |  | 1
FB601 | 600R@100MHz | Inductor_SMD:L_0603_1608Metric | BLM18KG601SN1D | Murata | 1
J103 | PACK_SENSE | Connector_JST:JST_XH_S7B-XH-A_1x07_P2.50mm_Horizontal | S7B-XH-A(LF)(SN) | JST | 1
J401 | BTN_EXT | Connector_JST:JST_PH_S2B-PH-K_1x02_P2.00mm_Horizontal | S2B-PH-K-S(LF)(SN) | JST | 1
J504 | ESTOP | Connector_JST:JST_PH_B2B-PH-K_1x02_P2.00mm_Vertical | B2B-PH-K-S(LF)(SN) | JST | 1
J601 | SWD | Connector_PinHeader_1.27mm:PinHeader_2x05_P1.27mm_Vertical_SMD | FTSH-105-01-L-DV-K | Samtec | 1
J602 | CAN | Connector_JST:JST_GH_BM04B-GHS-TBT_1x04-1MP_P1.25mm_Vertical | BM04B-GHS-TBT(LF)(SN)(N) | JST | 1
J603 | HALL | Connector_JST:JST_ZH_B6B-ZR_1x06_P1.50mm_Vertical | B6B-ZR(LF)(SN) | JST | 1
J701 | USB_C_16P | Connector_USB:USB_C_Receptacle_GCT_USB4105-xx-A_16P_TopMnt_Horizontal | USB4105-GF-A | GCT | 1
J901 | SERVO | Connector_PinHeader_2.54mm:PinHeader_1x03_P2.54mm_Vertical |  |  | 1
J902 | LIDAR_PWR | TerminalBlock_Phoenix:TerminalBlock_Phoenix_PT-1,5-2-3.5-H_1x02_P3.50mm_Horizontal | 1984617 | Phoenix Contact | 1
J903 | FAN | Connector:FanPinHeader_1x04_P2.54mm_Vertical |  |  | 1
J1001 | STACK_2x20 | Connector_PinSocket_2.54mm:PinSocket_2x20_P2.54mm_Vertical | SSQ-120-03-G-D | Samtec | 1
L401 | 22u | Inductor_SMD:L_Bourns-SRN4018 | SRN4018-220M | Bourns | 1
L701 | 1u | Inductor_SMD:L_Coilcraft_XAL5030-XXX | XAL5030-102MEB | Coilcraft | 1
Q201-Q208,Q302-Q306,Q502-Q505,Q507-Q510,Q512-Q515 | CSD18510Q5B | Package_TO_SOT_SMD:TDSON-8-1 | CSD18510Q5B | Texas Instruments | 25
Q301 | MMBT3904 | Package_TO_SOT_SMD:SOT-23 | MMBT3904LT1G | onsemi | 1
Q401,Q501,Q506,Q511 | 2N7002K | Package_TO_SOT_SMD:SOT-23 | 2N7002K | onsemi / Nexperia | 4
R201-R205 | 33 | Resistor_SMD:R_0805_2012Metric |  |  | 5
R206,R217,R310-R313,R403,R409,R532,R603,R604,R617,R619,R621,R810,R813,R814,R1005 | 1k | Resistor_SMD:R_0402_1005Metric |  |  | 18
R207,R306,R405,R408,R501-R503,R531,R534,R601,R602,R612,R622,R625,R701-R704,R708,R713,R803,R804,R808,R811,R1001,R1002 | 10k | Resistor_SMD:R_0402_1005Metric |  |  | 26
R208 | 750k | Resistor_SMD:R_0402_1005Metric |  |  | 1
R209,R210 | 470k | Resistor_SMD:R_0402_1005Metric |  |  | 2
R211,R216,R218 | 1M | Resistor_SMD:R_0402_1005Metric |  |  | 3
R212,R213,R302,R505,R513,R521,R533,R605,R606,R608,R610,R623,R705,R812,R906 | 100 | Resistor_SMD:R_0402_1005Metric |  |  | 15
R214 | 0.5m | Resistor_SMD:R_Shunt_Isabellenhuette_BVR4026 | BVR-Z-R0005-1.0 | Isabellenhuette | 1
R215 | 4.53k | Resistor_SMD:R_0402_1005Metric |  |  | 1
R301,R512,R520,R528 | 0.2m | Resistor_SMD:R_Shunt_Isabellenhuette_BVR4026 | BVR-Z-R0002-1.0 | Isabellenhuette | 4
R303 | 4.02k | Resistor_SMD:R_0402_1005Metric |  |  | 1
R304 | 39.2k | Resistor_SMD:R_0402_1005Metric |  |  | 1
R305 | 5.1k | Resistor_SMD:R_0402_1005Metric |  |  | 1
R307-R309,R401,R402,R404,R504,R607,R609,R611,R710,R801,R809,R901,R904,R907,R909,R911,R912 | 100k | Resistor_SMD:R_0402_1005Metric |  |  | 19
R314-R317,R508-R511,R516-R519,R524-R527 | 2.2 | Resistor_SMD:R_0402_1005Metric |  |  | 16
R318,R805 | 470 | Resistor_SMD:R_0402_1005Metric |  |  | 2
R319,R320 | 22 | Resistor_SMD:R_2512_6332Metric | CRCW251222R0FKEGHP | Vishay | 2
R406 | 10 | Resistor_SMD:R_0603_1608Metric |  |  | 1
R407 | 54.9k | Resistor_SMD:R_0402_1005Metric |  |  | 1
R506,R514,R522,R529,R709 | 39k | Resistor_SMD:R_0402_1005Metric |  |  | 5
R507,R515,R523,R530,R712 | 2.2k | Resistor_SMD:R_0402_1005Metric |  |  | 5
R613,R614,R616,R618,R620 | 4.7k | Resistor_SMD:R_0402_1005Metric |  |  | 5
R615 | 120 | Resistor_SMD:R_0402_1005Metric |  |  | 1
R624 | 220 | Resistor_SMD:R_0402_1005Metric |  |  | 1
R706 | 5.23k | Resistor_SMD:R_0402_1005Metric |  |  | 1
R707 | 30.1k | Resistor_SMD:R_0402_1005Metric |  |  | 1
R711 | 17.4k | Resistor_SMD:R_0402_1005Metric |  |  | 1
R802 | 12.0k | Resistor_SMD:R_0402_1005Metric |  |  | 1
R806,R807 | 47k | Resistor_SMD:R_0402_1005Metric |  |  | 2
R902 | 16.2k | Resistor_SMD:R_0402_1005Metric |  |  | 1
R903 | 15.8k | Resistor_SMD:R_0402_1005Metric |  |  | 1
R905 | 15.4k | Resistor_SMD:R_0402_1005Metric |  |  | 1
R908 | 732k | Resistor_SMD:R_0402_1005Metric |  |  | 1
R910 | 12k | Resistor_SMD:R_0402_1005Metric |  |  | 1
R1003,R1004 | 10 | Resistor_SMD:R_0402_1005Metric |  |  | 2
SW401 | POWER | Button_Switch_SMD:SW_Push_1P1T_NO_CK_KMR2 | KMR211NG LFS | C&K | 1
SW801 | FLASH | Button_Switch_SMD:SW_SPDT_PCM12 | PCM12SMTR | C&K | 1
TH501 | 10k B3380 | Resistor_SMD:R_0402_1005Metric | NCP15XH103F03RC | Murata | 1
U201 | BQ7791508 | Package_SO:TSSOP-24_4.4x7.8mm_P0.65mm | BQ7791508PWR | Texas Instruments | 1
U301 | TPS48111-Q1 | atlas:TI_DGX0019A_VSSOP-19_3x5.1mm_P0.5mm | TPS48111QDGXRQ1 | Texas Instruments | 1
U401 | TPS70933 | Package_TO_SOT_SMD:SOT-23-5 | TPS70933DBVR | Texas Instruments | 1
U402 | SN74LVC1G74 | Package_SO:VSSOP-8_2.3x2mm_P0.5mm | SN74LVC1G74DCUR | Texas Instruments | 1
U403 | 74LVC1G34 | Package_TO_SOT_SMD:SOT-353_SC-70-5 | SN74LVC1G34DCKR | Texas Instruments | 1
U404 | TLV75533P | Package_SON:WSON-6-1EP_2x2mm_P0.65mm_EP1x1.6mm | TLV75533PDRVR | Texas Instruments | 1
U501 | DRV8323RS | Package_DFN_QFN:Texas_RGZ0048A_VQFN-48-1EP_7x7mm_P0.5mm_EP5.15x5.15mm_ThermalVias | DRV8323RSRGZR | Texas Instruments | 1
U502 | 74LVC1G08 | Package_TO_SOT_SMD:SOT-353_SC-70-5 | SN74LVC1G08DCKR | Texas Instruments | 1
U601 | STM32F405RGT6 | Package_QFP:LQFP-64_10x10mm_P0.5mm | STM32F405RGT6 | STMicroelectronics | 1
U602 | LSM6DS3TR-C | Package_LGA:LGA-14_3x2.5mm_P0.5mm_LayoutBorder3x4y | LSM6DS3TR-C | STMicroelectronics | 1
U603 | SN65HVD230 | Package_SO:SOIC-8_3.9x4.9mm_P1.27mm | SN65HVD230DR | Texas Instruments | 1
U604 | 74AHCT1G125 | Package_TO_SOT_SMD:SOT-353_SC-70-5 | SN74AHCT1G125DCKR | Texas Instruments | 1
U701 | TPS25751D | atlas:Texas_REF0038A_WQFN-38-2EP_6x4mm_P0.4_Gap0.19 | TPS25751DREFR | Texas Instruments | 1
U702 | M24512 | Package_SO:SOIC-8_3.9x4.9mm_P1.27mm | M24512-RMN6TP | STMicroelectronics | 1
U703 | BQ25798 | Package_DFN_QFN:Texas_RQM0029A_VQFN-29_4x4mm_P0.4mm | BQ25798RQMR | Texas Instruments | 1
U801,U802 | TS3USB30E | Package_SO:MSOP-10_3x3mm_P0.5mm | TS3USB30EDGSR | Texas Instruments | 2
U803 | USB2514B | Package_DFN_QFN:QFN-36-1EP_6x6mm_P0.5mm_EP3.7x3.7mm | USB2514B-I/M2 | Microchip | 1
U804 | CP2102N-QFN24 | Package_DFN_QFN:QFN-24-1EP_4x4mm_P0.5mm_EP2.6x2.6mm | CP2102N-A02-GQFN24 | Silicon Labs | 1
U901 | TPSM63610 | atlas:TI_RDF0022A_B3QFN-22_6.5x7.5mm | TPSM63610RDFR | Texas Instruments | 1
U902 | TPS26600 | Package_SO:HTSSOP-16-1EP_4.4x5mm_P0.65mm_EP3.4x5mm | TPS26600PWPR | Texas Instruments | 1
U1001 | INA228 | Package_SO:MSOP-10_3x3mm_P0.5mm | INA228AIDGSR | Texas Instruments | 1
U1002 | 24AA02 | Package_TO_SOT_SMD:SOT-23-5 | 24AA02T-I/OT | Microchip | 1
Y601 | 8MHz | Crystal:Crystal_SMD_3225-4Pin_3.2x2.5mm |  |  | 1
Y801 | 24MHz | Crystal:Crystal_SMD_3225-4Pin_3.2x2.5mm |  |  | 1

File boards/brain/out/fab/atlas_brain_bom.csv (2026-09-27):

Designator | Value | Footprint | MPN | Manufacturer | Qty
BT1 | Battery_Holder_MS621FE-FL11E | antmicro-footprints:MS621FE-FL11E | MS621FE-FL11E | Seiko Instruments | 1
C1,C2 | C_Pol_100u_25V_KEMET-T521-D-107 | antmicro-footprints:C_Pol_EIA-X | T521D107M025ATE040 | KEMET | 2
C5,C122,C151,C152 | C_22u_25V_0805 | antmicro-footprints:C_0805_2012Metric | CL21A226MAYNNNE | Samsung Electro-Mechanics | 4
C6-C8,C25,C40,C41,C44,C48,C50,C78,C102,C104,C118,C119,C121,C124,C125,C130,C157 | C_100n_0402 | antmicro-footprints:C_0402_1005Metric | GRM155R61H104KE14D | Murata | 19
C9,C10,C13-C20 | C_220n_0402 | antmicro-footprints:C_0402_1005Metric | CC0402KRX5R6BB224 | YAGEO | 10
C11,C12,C21-C24 | C_10u_0603 | antmicro-footprints:C_0603_1608Metric | GRM188R61A106KE69D | Murata | 6
C77 | C_10n_0603 | antmicro-footprints:C_0603_1608Metric | 06031C103JAT2A | AVX | 1
C83,C116,C117,C137 | C_10u_0402 | antmicro-footprints:C_0402_1005Metric | CC0402MRX5R5BB106 | YAGEO | 4
C93,C123,C142 | C_1u_0402 | antmicro-footprints:C_0402_1005Metric | C1005X6S1A105K050BC | TDK | 3
C103,C120,C126-C129,C153,C154 | C_22u_16V_0603 | antmicro-footprints:C_0603_1608Metric_EIA | CL10A226MO7JZNC | Samsung Electro-Mechanics | 8
C134 | C_10u_25V_0603 | antmicro-footprints:C_0603_1608Metric | C1608X5R1E106M080AC | TDK | 1
C150 | C_1u_25V_0402 | antmicro-footprints:C_0402_1005Metric | GRM155R61E105KE11J | Murata | 1
C155,C156 | C_4u7_25V_0402 | antmicro-footprints:C_0402_1005Metric | GRM155C61E475ME15J | Murata | 2
C160 | C_1n_0402 | antmicro-footprints:C_0402_1005Metric | GRM1555C1H102JA01D | Murata | 1
C161 | C_1n_16V_X7R_0402 | antmicro-footprints:C_0402_1005Metric | C0402C102J4RACTU | KEMET | 1
C1001,C1002,C1302-C1306,C1308-C1311,C1313-C1317,C1319,C1324 | 100n | Capacitor_SMD:C_0402_1005Metric |  |  | 18
C1101 | 2.2n | Capacitor_SMD:C_0402_1005Metric |  |  | 1
C1102 | 4.7n | Capacitor_SMD:C_0402_1005Metric |  |  | 1
C1103,C1104,C1206,C1207 | 10u 25V | Capacitor_SMD:C_1206_3216Metric | GRM31CR71E106KA12L | Murata | 4
C1105,C1108,C1208,C1213 | 100n 50V | Capacitor_SMD:C_0402_1005Metric |  |  | 4
C1106,C1107 | 22u 25V | Capacitor_SMD:C_1210_3225Metric | GRM32ER71E226KE15L | Murata | 2
C1201 | 100p | Capacitor_SMD:C_0402_1005Metric |  |  | 1
C1202-C1204 | 2.2u 100V | Capacitor_SMD:C_1210_3225Metric | GRM32ER72A225KA35L | Murata | 3
C1205 | 22u 100V | Capacitor_SMD:CP_Elec_8x10.5 | EEE-FK2A220P | Panasonic | 1
C1209 | 2.2u 16V | Capacitor_SMD:C_0603_1608Metric |  |  | 1
C1210 | 47n | Capacitor_SMD:C_0402_1005Metric |  |  | 1
C1211,C1215 | 10n | Capacitor_SMD:C_0402_1005Metric |  |  | 2
C1212 | 330p | Capacitor_SMD:C_0402_1005Metric |  |  | 1
C1214,C1216 | 100n 100V | Capacitor_SMD:C_0805_2012Metric | GRM21BR72A104KAC4L | Murata | 2
C1217,C1323 | 1n 2kV | Capacitor_SMD:C_1206_3216Metric | GRM31BR73D102KW01L | Murata | 2
C1301,C1312 | 10u 10V | Capacitor_SMD:C_0603_1608Metric |  |  | 2
C1307,C1318 | 1u | Capacitor_SMD:C_0402_1005Metric |  |  | 2
C1320,C1321 | 27p | Capacitor_SMD:C_0402_1005Metric |  |  | 2
C1322 | 10n | Capacitor_SMD:C_0603_1608Metric |  |  | 1
D1,D26,D27,D51-D54,D62 | LED_G_0603_LTST-C190GKT | antmicro-footprints:LED_0603_1608Metric_G | LTST-C190GKT | Lite-On | 8
D22,D23,D55-D61 | TPD1E0B04_XDFN-2 | antmicro-footprints:XDFN-2_1x0.60mm | TPD1E0B04DPYR | Texas Instruments | 9
D29 | DF2S30FS_SOD | antmicro-footprints:SOD-923 | DF2S30FS | Toshiba | 1
D30-D33 | ESD9X5.0ST5G | antmicro-footprints:SOD-923 | ESD9X5.0ST5G | ON Semiconductor | 4
D34,D36,D37 | RB521S30T1G | antmicro-footprints:SOD-523 | RB521S30T1G | ON Semiconductor | 3
D1201 | SS2H10 | Diode_SMD:D_SMB | SS2H10-E3/52T | Vishay | 1
D1202,D1203 | SMBJ58A | Diode_SMD:D_SMB | SMBJ58A | Littelfuse | 2
H1,H2 | Spacer_Drill3.7mm_H6.5mm_9774065151R | antmicro-footprints:Spacer_Drill3.7mm_H6.5mm_9774065151R | 9774065151R | Würth Elektronik | 2
J1 | Bus_M.2_2199230-6 | antmicro-footprints:Bus_M.2_Socket_Key_E_TE_2199230-6 | 2199230-6 | TE Connectivity | 1
J2 | Bus_M.2_1-2199230-6 | antmicro-footprints:Bus_M.2_Socket_Key_M_TE_1-2199230-6 | 1-2199230-6 | TE Connectivity | 1
J6 | Bus_RJ45_5-2337992-8 | antmicro-footprints:RJ45_X-2337992-8_Horizontal | 5-2337992-8 | TE Connectivity | 1
J10 | Molex_PicoBlade_1x4_0533980471 | antmicro-footprints:Conn_Molex_PicoBlade_1x4_0533980471 | 0533980471 | Molex | 1
J14 | JST_SH_1x4_SM04B-SRSS-TB-LF-SN | antmicro-footprints:Conn_JST_SH_1x4_SM04B-SRSS-TB-LF-SN | SM04B-SRSS-TB(LF)(SN) | JST Automotive Connectors | 1
J15 | Bus_DDR4_SODIMM_CUSTOM_Jetson-Orin-H9.2mm-socket | antmicro-footprints:TE_2309413 | 2309413-1 | TE Connectivity | 1
J1001 | STACK_2x20 | Connector_PinHeader_2.54mm:PinHeader_2x20_P2.54mm_Vertical | TSW-120-xx-G-D (post length for the 20 mm stack, see notes) | Samtec | 1
J1301 | LIDAR | antmicro-footprints:RJ45_X-2337992-8_Horizontal | 5-2337992-8 | TE Connectivity | 1
L1 | L_560n_17.7A_Bourns-SRP5030CA | antmicro-footprints:L_Bourns-SRP5030CA | SRP5030CA-R56M | Bourns | 1
L4 | L_1u_20A_Bourns-SRP6050CA | antmicro-footprints:L_Bourns-SRP6050CA | SRP6050CA-1R0M | Bourns | 1
L1201 | 47u | Inductor_SMD:L_Coilcraft_XAL7070-XXX | XAL7070-473MEC | Coilcraft | 1
L1301 | 3.3u | Inductor_SMD:L_1008_2520Metric | LQM2HPN3R3MG0L | Murata | 1
Q5,Q7-Q11,Q22,Q1002-Q1004 | PJE138K | antmicro-footprints:SOT-523 | PJE138K_R1_00001 | PANJIT | 10
Q6,Q16,Q18,Q1001 | SSM3J332R | antmicro-footprints:SOT-23-3 | SSM3J332R,LF | Toshiba | 4
Q14 | BCM857BS-7-F | antmicro-footprints:SOT-363 | BCM857BS-7-F | Diodes Incorporated | 1
Q1201,Q1202 | CSD19538Q3A | Package_SON:VSON-8_3.3x3.3mm_P0.65mm_NexFET | CSD19538Q3A | Texas Instruments | 2
R1,R13,R14,R16-R20,R29,R52,R215-R218,R260,R264,R268 | R_0R_0402 | antmicro-footprints:R_0402_1005Metric | ERJ2GE0R00X | Panasonic | 17
R21,R22,R25,R195 | R_4x0R_0201_array | antmicro-footprints:R_Array_4x0201_Panasonic_EXB18V | EXB-18VR000X | Panasonic | 4
R39,R147,R151,R152,R186,R187,R191,R223,R231,R236 | R_200R_0402 | antmicro-footprints:R_0402_1005Metric | CR0402-FX-2000GLF | Bourns | 10
R80,R164,R165 | R_4k7_0402 | antmicro-footprints:R_0402_1005Metric | CR0402-FX-4701GLF | Bourns | 3
R143,R172,R178,R287 | R_0R_22.4A_0603 | antmicro-footprints:R_0603_1608Metric | PMR03EZPJ000 | ROHM Semiconductor | 4
R169 | R_2k7_0402 | antmicro-footprints:R_0402_1005Metric | CR0402-FX-2701GLF | Bourns | 1
R170 | R_73k2_0402 | antmicro-footprints:R_0402_1005Metric | CR0402-FX-7322GLF | Bourns | 1
R173,R176,R237,R239 | R_499k_0402 | antmicro-footprints:R_0402_1005Metric | CR0402-FX-4993GLF | Bourns | 4
R177 | R_45k3_0402 | antmicro-footprints:R_0402_1005Metric | CR0402-FX-4532GLF | Bourns | 1
R181,R188,R189,R219,R232,R238,R242,R251,R255,R259,R269,R275 | R_10k_0402 | antmicro-footprints:R_0402_1005Metric | CR0402-FX-1002GLF | Bourns | 12
R190 | R_15k_0402 | antmicro-footprints:R_0402_1005Metric | CR0402-FX-1502GLF | Bourns | 1
R222,R230,R249,R274,R285 | R_100k_0402 | antmicro-footprints:R_0402_1005Metric | CR0402-FX-1003GLF | Bourns | 5
R256 | R_1k_0402 | antmicro-footprints:R_0402_1005Metric | CR0402-FX-1001GLF | Bourns | 1
R257,R258,R261 | R_200k_0402 | antmicro-footprints:R_0402_1005Metric | CR0402-FX-2003GLF | Bourns | 3
R263 | R_20k_0402 | antmicro-footprints:R_0402_1005Metric | CR0402-FX-2002GLF | Bourns | 1
R272 | R_470k_0402 | antmicro-footprints:R_0402_1005Metric | CR0402-FX-4703GLF | Bourns | 1
R273,R276 | R_0R_0603 | antmicro-footprints:R_0603_1608Metric | CR0603-J/-000ELF | Bourns | 2
R283,R284 | R_560R_0402 | antmicro-footprints:R_0402_1005Metric | CR0402-FX-5600GLF | Bourns | 2
R286 | R_470R_0402 | antmicro-footprints:R_0402_1005Metric | CR0402-FX-4700GLF | Bourns | 1
R294 | R_2k2_0402 | antmicro-footprints:R_0402_1005Metric | CR0402-FX-2201GLF | Bourns | 1
R1001,R1002 | 100k | Resistor_SMD:R_0402_1005Metric |  |  | 2
R1003,R1004 | 33 | Resistor_SMD:R_0402_1005Metric |  |  | 2
R1101 | 150k | Resistor_SMD:R_0402_1005Metric |  |  | 1
R1102,R1205,R1207,R1209,R1303-R1305 | 10k | Resistor_SMD:R_0402_1005Metric |  |  | 7
R1103 | 665 | Resistor_SMD:R_0402_1005Metric |  |  | 1
R1201 | 0.025 | Resistor_SMD:R_1206_3216Metric |  |  | 1
R1202 | 634 | Resistor_SMD:R_0402_1005Metric |  |  | 1
R1203 | 73.2k | Resistor_SMD:R_0402_1005Metric |  |  | 1
R1204 | 510k | Resistor_SMD:R_0603_1608Metric |  |  | 1
R1206 | 56k | Resistor_SMD:R_0402_1005Metric |  |  | 1
R1208 | 15.8k | Resistor_SMD:R_0402_1005Metric |  |  | 1
R1210,R1211 | 0.51 | Resistor_SMD:R_0805_2012Metric |  |  | 2
R1212 | 22.1 | Resistor_SMD:R_0603_1608Metric |  |  | 1
R1213 | 47 | Resistor_SMD:R_0603_1608Metric |  |  | 1
R1214 | 0 | Resistor_SMD:R_1206_3216Metric |  |  | 1
R1215,R1216,R1306-R1309 | 75 | Resistor_SMD:R_0603_1608Metric |  |  | 6
R1301 | 12.0k | Resistor_SMD:R_0402_1005Metric |  |  | 1
R1302 | 2.00k | Resistor_SMD:R_0402_1005Metric |  |  | 1
R1310-R1312 | 200 | Resistor_SMD:R_0402_1005Metric |  |  | 3
S1-S5 | SW_KMR211NGLFS_SMD | antmicro-footprints:SW_KMR211NGLFS_SMD | KMR211NGLFS | C&K | 5
SP7,SP8 | Spacer_Drill3.7mm_H2.5mm_9774025151R | antmicro-footprints:Spacer_Drill3.7mm_H2.5mm_9774025151R | 9774025151R | Würth Elektronik | 2
SW1 | SW_SPDT_PCM12SMTR | antmicro-footprints:PCM12SMTR | PCM12SMTR | C&K | 1
U1,U40 | SIC431AED-T1-GE3 | antmicro-footprints:MLP44-24L_4x4x0.75mm | SIC431AED-T1-GE3 | Vishay | 2
U4,U33 | NTS0102_XSON | antmicro-footprints:XSON-8_1x1.95mm_P0.5mm | NTS0102GT | NXP | 2
U29,U48,U1101 | TPS259474 | antmicro-footprints:VQFN-HR-10_2x2mm | TPS259474ARPWR | Texas Instruments | 3
U30 | TPD4E05U06QDQARQ1 | antmicro-footprints:USON-10_2.5x1mm_P0.5mm | TPD4E05U06QDQARQ1 | Texas Instruments | 1
U34 | PCAL6408A_VQFN | antmicro-footprints:VQFN-16-1EP_3x3mm_P0.5mm_EP1.68x1.68mm | PCAL6408ABSHP | NXP | 1
U35 | AP22653_DFN | antmicro-footprints:DFN-6-1EP_2x2mm_P0.65mm_EP1x1.6mm | AP22653FDZ-7 | Diodes Incorporated | 1
U37 | 74LVC2G14_SOT457 | antmicro-footprints:SOT-23-6 | 74LVC2G14GV,125 | Nexperia | 1
U38 | 74LVC1G175_SOT457 | antmicro-footprints:SOT-23-6 | 74LVC1G175GV,125 | Nexperia | 1
U41 | NCP730BMT330_WSON | antmicro-footprints:WSON-6-1EP_2x2mm_P0.65mm | NCP730BMT330TBG | ON Semiconductor | 1
U42 | TPS7A0518P_SOT23-5 | antmicro-footprints:SOT-23-5 | TPS7A0518PDBVT | Texas Instruments | 1
U1001 | NTS0102 | antmicro-footprints:XSON-8_1x1.95mm_P0.5mm | NTS0102GT | NXP | 1
U1201 | LM5155 | Package_SON:WSON-12-1EP_3x2mm_P0.5mm_EP1x2.65 | LM5155DSSR | Texas Instruments | 1
U1202 | TPS23861 | Package_SO:TSSOP-28_4.4x9.7mm_P0.65mm | TPS23861PWR | Texas Instruments | 1
U1301 | LAN7800 | Package_DFN_QFN:QFN-48-1EP_7x7mm_P0.5mm_EP5.3x5.3mm_ThermalVias | LAN7800-I/Y9X | Microchip | 1
Y1 | Oscillator_32.768kHz_ECS_2520MV | antmicro-footprints:Oscillator_SMD_ECS_2520MV_2.5x2mm | ECS-327MVATX-2-CN-TR3 | ECS Inc. International | 1
Y1301 | 25MHz | Crystal:Crystal_SMD_3225-4Pin_3.2x2.5mm | ABM8-25.000MHZ-B2-T | Abracon | 1

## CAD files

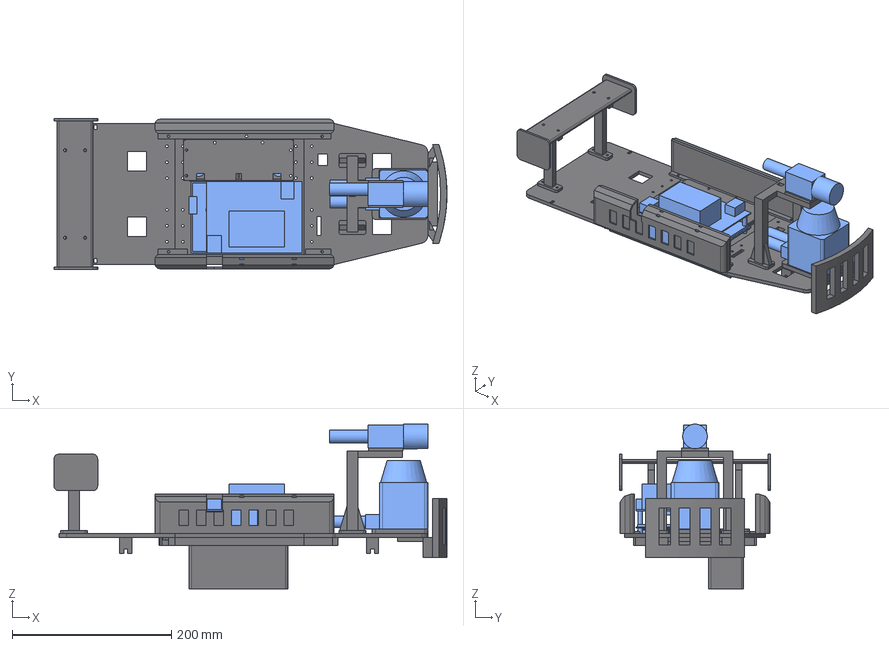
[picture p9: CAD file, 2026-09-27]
mech/out/step/assembly_kit_and_components.step
494.0 x 190.0 x 207.2 mm
deck_rear
deck_mid
deck_front
splice_rear_right
splice_rear_left
splice_front_right
splice_front_left
lidar_plinth
bumper
camera_arch
camera_cradle
side_pod_left
side_pod_right
wing_strut_left
wing_strut_right
wing_blade
pack_box
pack_lid
cell_holder_bottom
cell_holder_top
lidar
lidar_connectors
camera
camera_plug
drive_pcb
drive_fets_bottom
drive_standoffs_7mm
esc_heatsink
drive_bulk_caps
drive_top_parts
usb_c_and_button
brain_pcb
brain_standoffs_20mm
nvme_2280
jetson_module_and_sink
rj45_poe_camera
rj45_lidar
stack_header
fan_40mm
cells_4s3p

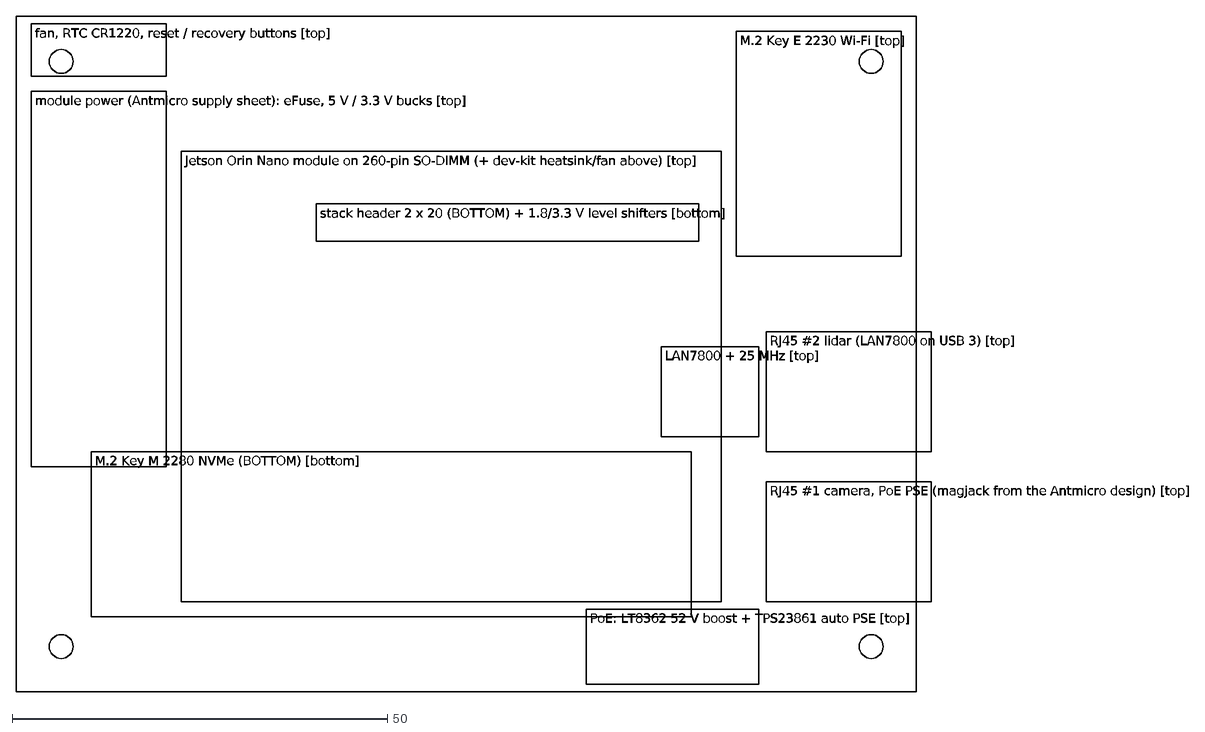
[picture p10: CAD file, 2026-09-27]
boards/brain/atlas_brain_outline.dxf
Jetson Orin Nano module on 260-pin SO-DIMM (+ dev-kit heatsink/fan above) [top]
M.2 Key M 2280 NVMe (BOTTOM) [bottom]
M.2 Key E 2230 Wi-Fi [top]
RJ45 #1 camera, PoE PSE (magjack from the Antmicro design) [top]
RJ45 #2 lidar (LAN7800 on USB 3) [top]
PoE: LT8362 52 V boost + TPS23861 auto PSE [top]
LAN7800 + 25 MHz [top]
module power (Antmicro supply sheet): eFuse, 5 V / 3.3 V bucks [top]
fan, RTC CR1220, reset / recovery buttons [top]
stack header 2 x 20 (BOTTOM) + 1.8/3.3 V level shifters [bottom]

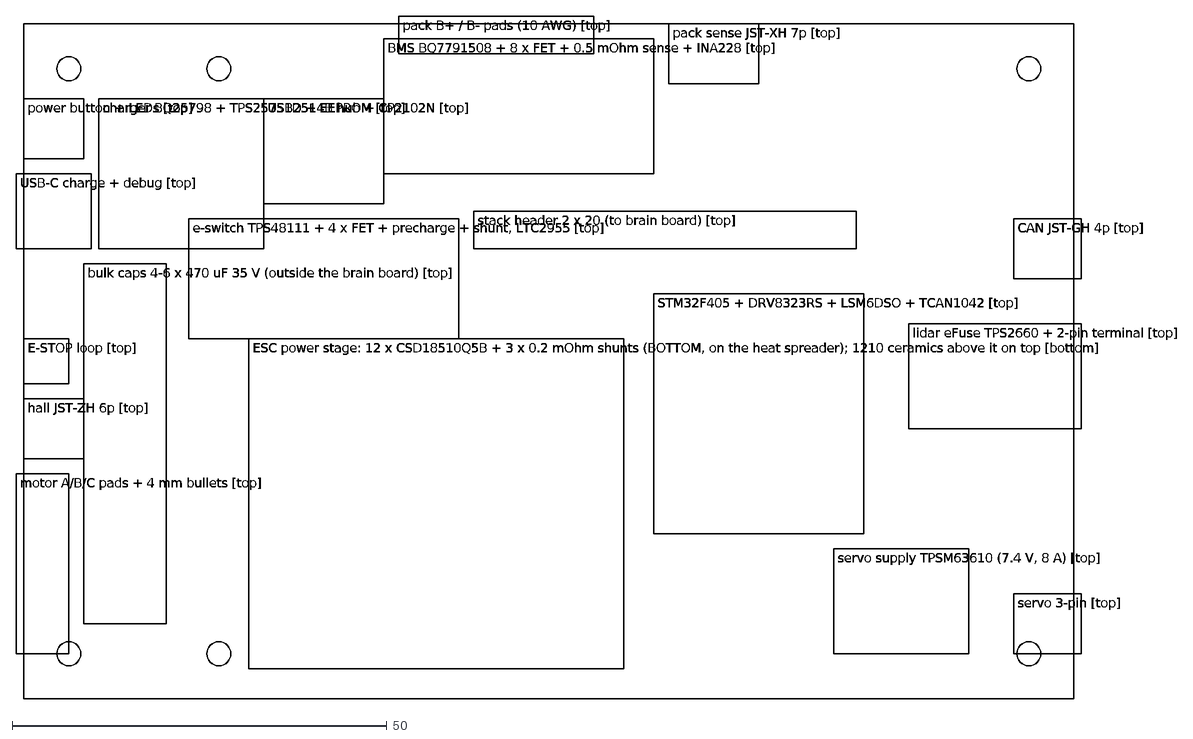
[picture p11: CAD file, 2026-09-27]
boards/drive/atlas_drive_outline.dxf
ESC power stage: 12 x CSD18510Q5B + 3 x 0.2 mOhm shunts (BOTTOM, on the heat spreader); 1210 ceramics above it on top [bottom]
bulk caps 4-6 x 470 uF 35 V (outside the brain board) [top]
motor A/B/C pads + 4 mm bullets [top]
hall JST-ZH 6p [top]
E-STOP loop [top]
USB-C charge + debug [top]
power button + LEDs [top]
charger BQ25798 + TPS25751D + EEPROM [top]
USB2514B hub + CP2102N [top]
BMS BQ7791508 + 8 x FET + 0.5 mOhm sense + INA228 [top]
pack B+ / B- pads (10 AWG) [top]
pack sense JST-XH 7p [top]
e-switch TPS48111 + 4 x FET + precharge + shunt, LTC2955 [top]
STM32F405 + DRV8323RS + LSM6DSO + TCAN1042 [top]
stack header 2 x 20 (to brain board) [top]
servo supply TPSM63610 (7.4 V, 8 A) [top]
servo 3-pin [top]
lidar eFuse TPS2660 + 2-pin terminal [top]
CAN JST-GH 4p [top]

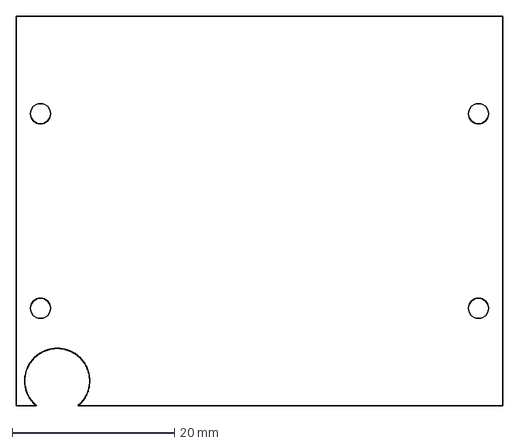
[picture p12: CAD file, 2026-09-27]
mech/out/dxf/heat_spreader.dxf
60.0 x 48.0 mm

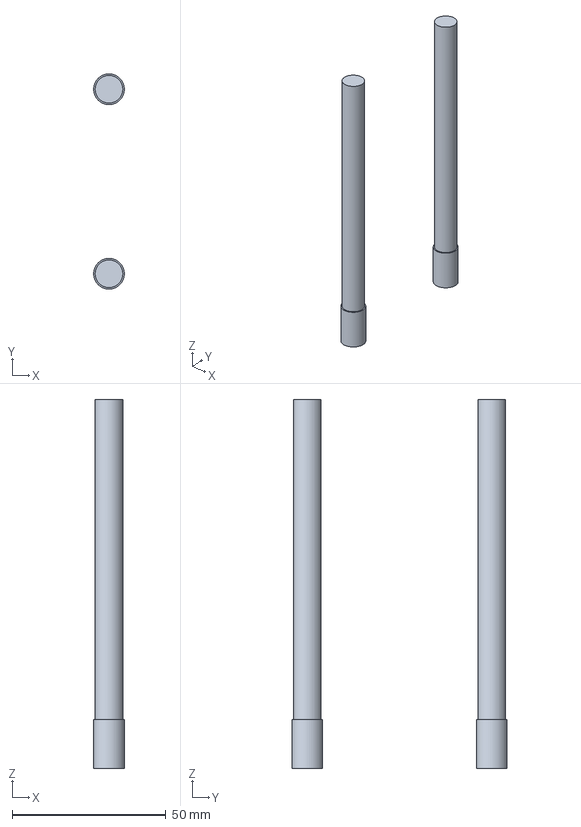
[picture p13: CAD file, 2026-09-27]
mech/out/step/bought_antennas.step
9.99 x 70.0 x 120.0 mm

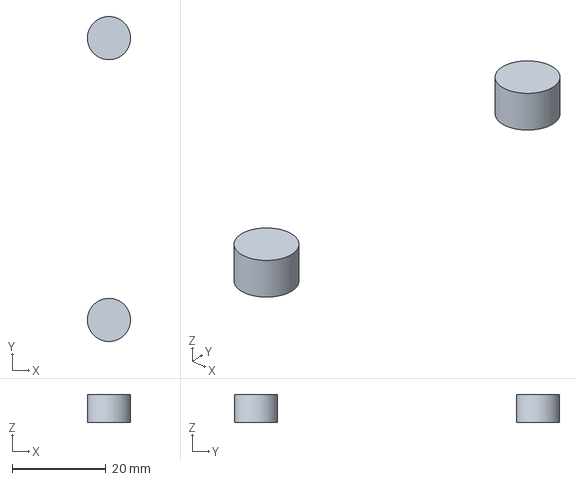
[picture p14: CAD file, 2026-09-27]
mech/out/step/bought_antenna_jacks.step
9.19 x 69.2 x 6.00 mm

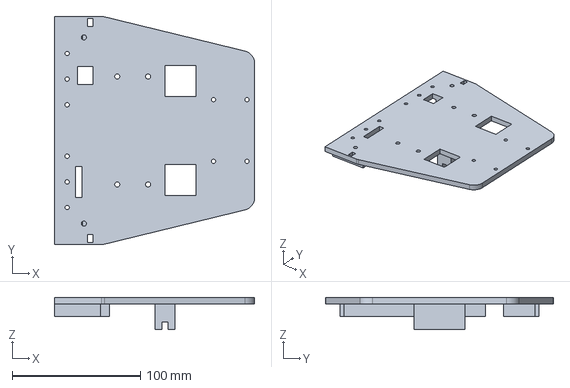
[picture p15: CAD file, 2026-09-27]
mech/out/step/deck_front.step
156.0 x 177.5 x 25.2 mm

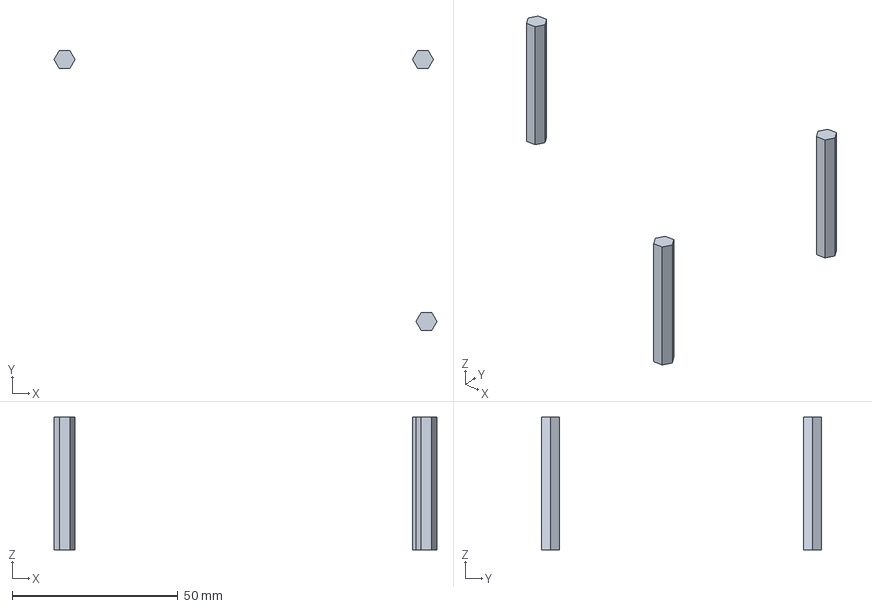
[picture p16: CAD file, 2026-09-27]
mech/out/step/bought_canopy_standoffs.step
115.4 x 84.4 x 40.0 mm

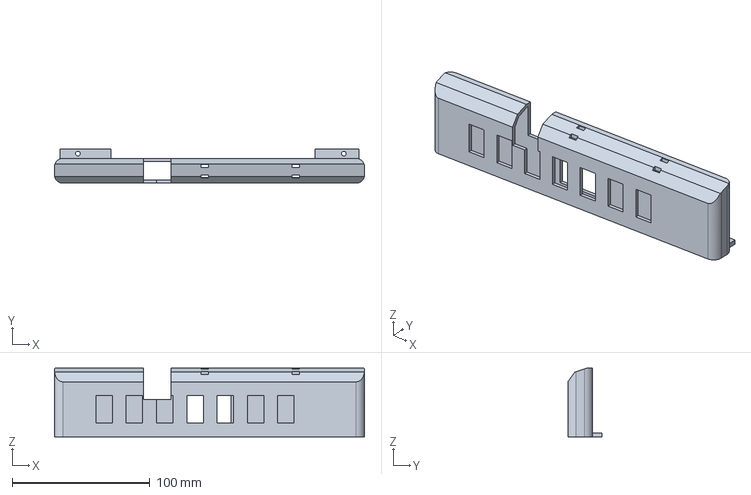
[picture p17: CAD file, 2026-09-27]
mech/out/step/side_pod_right.step
225.0 x 25.0 x 50.0 mm

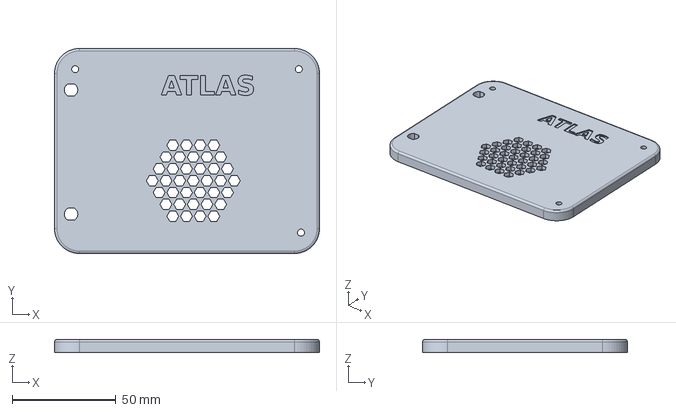
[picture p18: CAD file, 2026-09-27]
mech/out/step/stack_canopy.step
128.0 x 99.0 x 6.40 mm

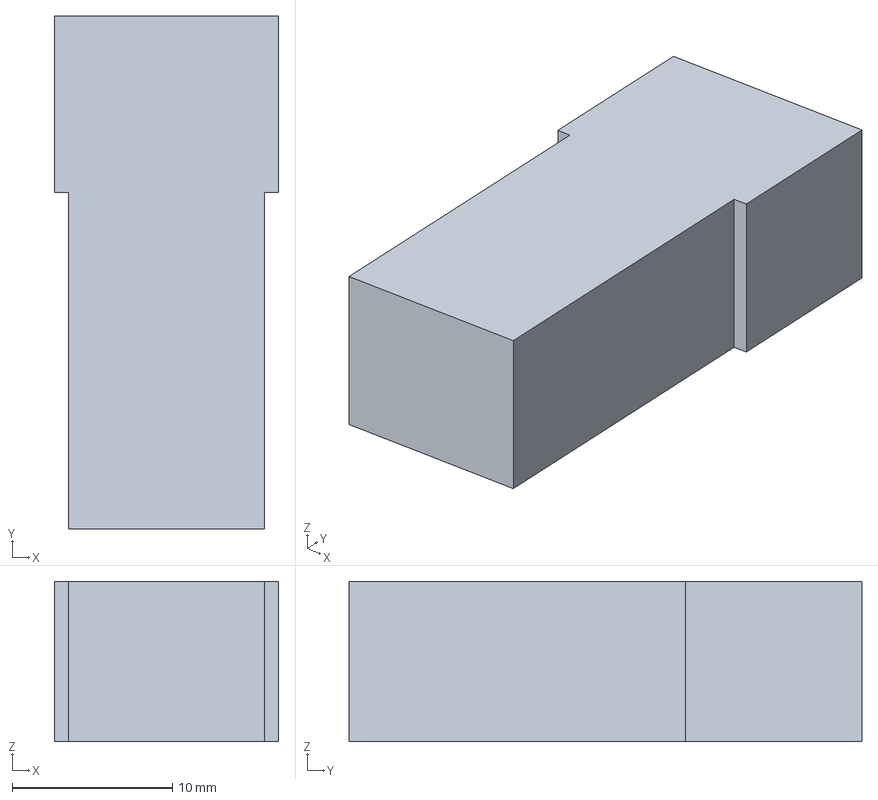
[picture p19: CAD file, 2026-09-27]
mech/out/step/bought_rj45_plug_lidar.step
14.0 x 32.0 x 10.0 mm

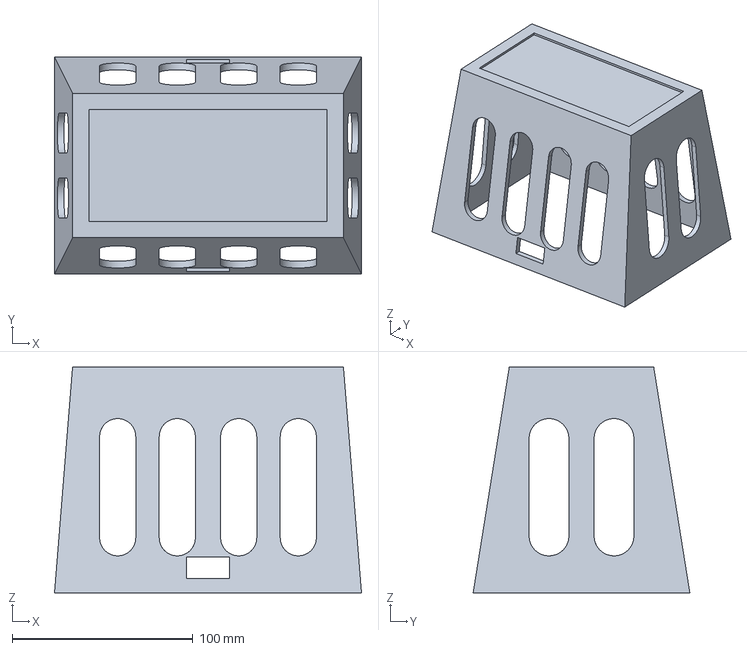
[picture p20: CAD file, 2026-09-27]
mech/out/step/bench_stand.step
170.0 x 120.0 x 125.0 mm

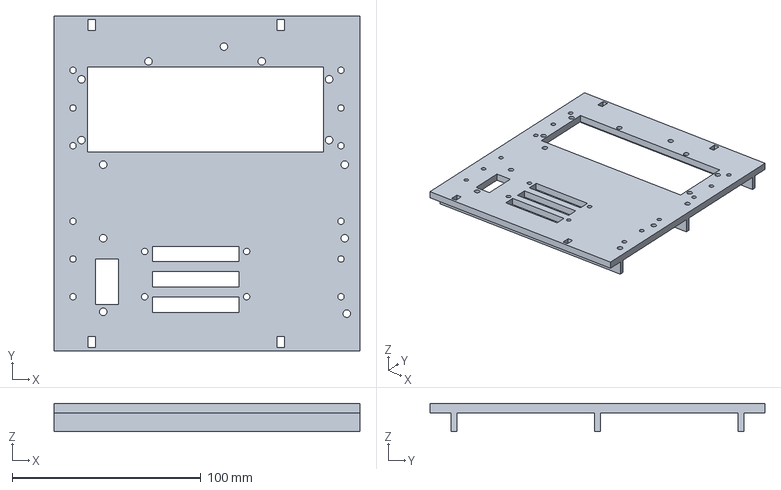
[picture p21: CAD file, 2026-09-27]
mech/out/step/deck_mid.step
162.0 x 177.5 x 15.0 mm

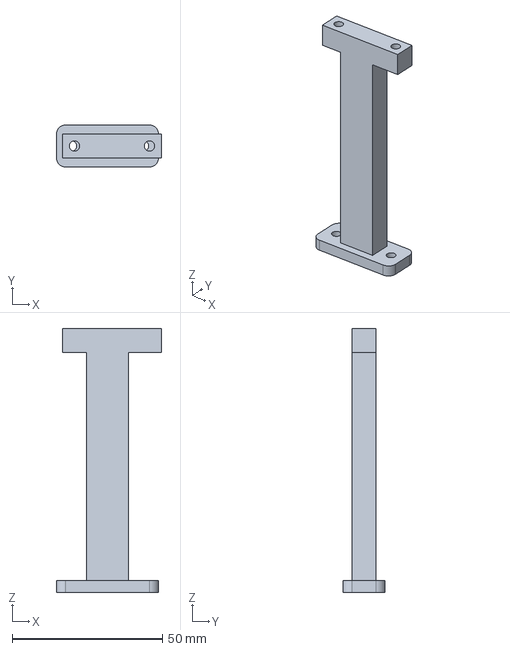
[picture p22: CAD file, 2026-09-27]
mech/out/step/wing_strut_right.step
35.0 x 14.0 x 88.0 mm

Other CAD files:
mech/out/step/bought_rj45_plug_camera.step
mech/out/step/side_pod_left.step
mech/out/step/splice_rear_left.step
mech/out/step/wing_blade.step
mech/out/step/bumper.step
mech/out/step/camera_arch.step
mech/out/step/camera_cradle.step
mech/out/step/camera_cradle_down10.step
mech/out/step/camera_cradle_down5.step
mech/out/step/cell_holder_bottom.step
mech/out/step/cell_holder_top.step
mech/out/step/chassis_keepouts_estimate.step
mech/out/step/deck_rear.step
mech/out/step/fit_coupon_front.step
mech/out/step/fit_coupon_rear.step
mech/out/step/lidar_plinth.step
mech/out/step/pack_box.step
mech/out/step/pack_lid.step
mech/out/step/post_washer.step
mech/out/step/splice_front_left.step
mech/out/step/splice_front_right.step
mech/out/step/splice_rear_right.step
mech/out/step/wing_strut_left.step
mech/out/stl/bench_stand.stl
mech/out/stl/bumper.stl
mech/out/stl/camera_arch.stl
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

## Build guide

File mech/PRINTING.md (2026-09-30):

# Printing the kit (P1S, PETG-CF)

The STLs in `out/stl` are not all in a printable orientation. On Sept 30 the bumper failed: its flange sat 20 mm
above the bed with nothing under it. An overhang audit of every STL found the same kind of problem in six more
parts. The fix is in the slicing, not the CAD: a few parts are turned upside down and the rest get tree supports.
Scripts live on the laptop in `~/slice_work` (`slice_carv2_fixed.sh`, `stl_flip.py`, `upload_fixed.sh`).

| part | problem in `out/stl` orientation | how to print it |
| --- | --- | --- |
| bumper | 38 x 80 mm flange floating 20 mm up | as is, tree supports from the plate, 5 mm brim |
| camera_arch | top bar floating 96 mm up (70 x 72 mm) | upside down (bar on the bed), supports under the foot pads |
| pack_box | printed floor-up (42 x 121 mm bridge at 70 mm) | upside down (floor on the bed, open end up), supports under the screw tabs |
| side_pod_left / _right | sloped walls, 1,900-2,100 mm2 of overhang | upside down, tree supports from the plate |
| wing_blade | 41 x 184 mm blade 7 mm above the bed | as is, supports under the blade |
| wing_strut_left / _right | 33 x 84 mm bar 3 mm above the bed | as is, supports under the bar |
| lidar_plinth | 28 x 38 mm pocket ceiling 4 mm up | as is, no supports (short bridge) |
| stack_canopy | only the 0.6 mm engraving | as is, no supports |
| deck pieces, splices, washers, fit coupons, cell holders, pack lid, camera cradles | fine | as is |

Support settings: tree(auto), build plate only, bridges up to 10 mm unsupported, 0.25 mm top/bottom gap
(PETG-CF), 5 mm outer brim on the supported plates.

Plates on the printer (`/carv2/`), all PETG-CF, 0.4 mm hardened nozzle:

| file | parts | time | filament |
| --- | --- | --- | --- |
| P1S_CarV2_Bumper_v2 | bumper (5 walls, 40 %) | 4 h 16 m | 92 g |
| P1S_CarV2_Arch_Struts | camera arch (flipped), 2 wing struts | 4 h 3 m | 89 g |
| P1S_CarV2_Plinth_Cradle_Canopy | lidar plinth, camera cradle (0 deg), stack canopy | 2 h 0 m | 57 g |
| P1S_CarV2_Side_Pods | both side pods (flipped), 3 walls 20 % | 5 h 38 m | 157 g |
| P1S_CarV2_Wing_Lid | wing blade, pack lid, 3 walls 20 % | 3 h 34 m | 81 g |
| P1S_CarV2_Pack_Box_v2 | pack box (flipped), 3 walls 30 % | 2 h 45 m | 74 g |

Unchanged from before: the three deck pieces, splices + washers, fit coupons, cell holders. The old
Mounts_Canopy, Bumper, Pods_Wing_Lid and Pack_Box files get renamed `OLD_DONT_PRINT_...` on the card by `upload_fixed.sh`.

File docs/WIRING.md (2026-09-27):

# Wiring: every cable, where it runs and how long it is

The lengths come from the cable paths in `mech/extras.py`. Each path is drawn through the car model and checked
against the kit, the boards, the new parts and the chassis keep-outs, and none of them hit anything
(`mech/out/extras_report.json`, `cable_interference`). "Routed" is the length of the modelled path. The last
column adds 10 % and 20 mm:

- For a lead you make, it is the length to cut.
- For a part's own lead or a bought cable, it is the shortest that reaches.

The chassis numbers these paths depend on are estimates (MEASURE_FIRST.md), so cut the 12 AWG and 10 AWG leads
only after the car is measured.

| cable | from | to | what | routed mm | length mm |
| --- | --- | --- | --- | ---: | --- |
| Camera | brain board J6 (RJ45, PoE port) | camera M12 | M12 X-coded 8-pin to RJ45, Cat6a (camera data and PoE power) | 270 | needs at least 320 |
| Lidar Ethernet | brain board J1301 (RJ45) | lidar Ethernet M12 | donor SICK M12 D-coded 4-pin to RJ45 (TiM561 Ethernet) | 94 | needs at least 130 |
| Lidar power | drive board J902 (2-pin terminal) | lidar power M12 | donor SICK M12 power cable, cut and stripped into the terminal | 49 | needs at least 80 |
| Motor phase A | drive board J501 (wire pad) | motor phase A | 12 AWG silicone, phase A, 4 mm bullet at the motor | 215 | cut to 260 |
| Motor phase B | drive board J502 (wire pad) | motor phase B | 12 AWG silicone, phase B, 4 mm bullet at the motor | 204 | cut to 250 |
| Motor phase C | drive board J503 (wire pad) | motor phase C | 12 AWG silicone, phase C, 4 mm bullet at the motor | 173 | cut to 220 |
| Motor hall sensor | drive board J603 | motor sensor port | motor's own sensor lead (6-pin, JST-ZH assumed) | 128 | needs at least 170 |
| Steering servo | drive board J901 | steering servo | servo's own 3-wire lead | 92 | needs at least 130 |
| Pack + | pack + strip (under the lid) | drive board J101 B+ | 10 AWG silicone, pack + (G4 end strip) to B+ | 94 | cut to 130 |
| Pack - | pack - strip (under the lid) | drive board J102 B- | 10 AWG silicone, pack - (G1 end strip) to B- | 68 | cut to 100 |
| Pack sense lead | pack taps B0-B4 and NTC | drive board J103 | 7-wire 24 AWG sense lead, JST-XH 7-pin at the board | 60 | cut to 90 |
| Side-pod fan | 40 mm fan (right pod) | drive board J903 | fan lead, 4-pin (fan to the drive board) | 56 | needs at least 90 |
| Wi-Fi antenna 1 | M.2 Wi-Fi card (under the Jetson module) | antenna jack, canopy rear left | MHF4 to RP-SMA bulkhead pigtail, 15 cm, 1.13 mm coax | 80 | needs at least 110 |
| Wi-Fi antenna 2 | M.2 Wi-Fi card (under the Jetson module) | antenna jack, canopy rear right | MHF4 to RP-SMA bulkhead pigtail, 15 cm, 1.13 mm coax | 67 | needs at least 100 |

## How each one runs

- **Camera.**
  - The plug goes straight out of J6 through the slot in the right side pod.
  - The cable turns up and forward, lies along the pod's top (zip-tie slot pairs at x 4 and 70) and climbs to
    the camera's M12 plug behind the camera arch.
  - The LUCID cable on the parts list is 2 m, which leaves about 1.7 m to coil. Tie the coil flat on the rear
    deck under the wing, away from the lidar's field of view.
  - A shorter M12 X-coded to RJ45 cable (0.5 m) avoids the coil; it must be rated for PoE.
- **Lidar Ethernet.**
  - From the TiM561's left M12 plug, under the camera arch, back and up to J1301.
  - J1301 opens toward the car's left, so the plug and boot point left over the pack lid.
  - The donor cable is longer than the run: coil the rest on the deck behind the arch, below the scan plane.
- **Lidar power.**
  - From the right M12 plug, straight back to the J902 terminal at the drive board's front edge.
  - Wire the terminal before the brain board goes on: its screws are under the brain board's front edge.
- **Motor phases and hall lead.**
  - The three 12 AWG pigtails leave their pads toward the right edge and run back along the drive board.
  - They pass over its rear edge and forward again in the 7 mm gap under it, then down through the deck opening
    at x -58 to -46.
  - Under the deck they run out to the motor's end bell. The bullets sit on the end bell at 120 degrees.
  - The hall lead follows the same route to the sensor port.
- **Servo.** Forward from J901, down through the new 5 x 24 mm deck slot at x 98.5 to 103.5, then under the
  cross rib to the servo.
- **Pack.**
  - The 10 AWG leads come up through the lid slots and go down into the drive board's through-hole wire pads:
    pack + (the front end, G4) to B+, pack - (the rear end, G1) to B-.
  - The pack - lead crosses over the pack + lead.
  - The 7-wire sense lead comes out of the middle slot to J103.
  - Connect the sense lead first (PACK_BUILD.md, step 6).
- **Side-pod fan.**
  - The fan's lead comes in through the fan window in the right pod and runs back to J903.
  - It passes inboard of the brain board's 20 mm standoff at the rear-right corner.
- **Wi-Fi.**
  - Two pigtails run from the M.2 card under the Jetson module to the RP-SMA jacks in the canopy.
  - The dev kit's card (AzureWave AW-CB375NF) has MHF4 jacks, so the ordered pigtails are MHF4, 15 cm. The
    slack, 7 to 8 cm each, coils beside the Jetson module.
- **E-stop.** Nothing runs here unless an E-stop button is fitted. Close J504 with a JST-PH wire loop, or the
  motor will not run.

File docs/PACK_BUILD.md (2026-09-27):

# Building the 4S3P 18650 pack

Twelve Molicel P28A (2800 mAh, 35 A, 18.6 x 65.2 mm, 46 g; 18650batterystore.com), 4S3P:
14.4 V nominal, 16.8 V full, 8.4 Ah, about 121 Wh, 105 A maximum. Buy 14 so there are two
spares from the same batch. Do not mix cells from different batches or with different
states of charge; check every cell reads within 0.02 V of the others before welding.

Build it with an adult supervising, on a non-flammable bench, with a bucket of sand and a
fire extinguisher nearby. Nothing in this pack is protected until the BMS on the drive board is connected, so
the strips and leads are live the moment the first joint is welded.

## Layout

Cells stand upright in a 2 x 6 grid. Column i = 0 is the rear of the car, i = 5 the front;
row j = 0 is the side toward the drive board, j = 1 the outboard side. "Facing up" is the
terminal on top.

| group | cells (i, j) | facing up | top strip | bottom strip |
| --- | --- | --- | --- | --- |
| G1 | (0,0) (0,1) (1,0) | - | PACK- tab + B0 tap | G1+ to G2- (B1) |
| G2 | (1,1) (2,0) (2,1) | + | G2+ to G3- (B2) | G1+ to G2- (B1) |
| G3 | (3,0) (3,1) (4,0) | - | G2+ to G3- (B2) | G3+ to G4- (B3) |
| G4 | (4,1) (5,0) (5,1) | + | PACK+ tab + B4 tap | G3+ to G4- (B3) |

Top strips: one over G1 (pack minus), one over G2 + G3 (series joint B2), one over G4 (pack
plus). Bottom strips: one over G1 + G2 (series joint B1), one over G3 + G4 (series joint B3).
Both main terminals end up on top at the two ends, so the 10 AWG leads leave straight up
through the lid slots. The two bottom taps (B1, B3) run up the grooves inside the box wall on
the drive-board side.

## Steps

1. Print `cell_holder_bottom.stl`, `cell_holder_top.stl`, `pack_box.stl`, `pack_lid.stl`.
   The holders have 18.95 mm pockets and 14 mm windows for the welder.
2. Put a fish-paper ring on every positive cap. Load the cells in the bottom holder with the
   orientation in the table, then press the top holder on.
3. Weld two layers of 0.2 x 8 mm pure nickel on every series strip (B1, B2, B3) and one layer
   on the end strips, two to four welds per cell. Test-weld on a spare first: the weld should
   tear the nickel, not peel off.
4. Solder the 10 AWG PACK+ and PACK- leads to the end strips on top, away from the cell caps
   (heat the strip, not the cell). Solder the 24 AWG sense wires: B0 (pack minus) through B4
   (pack plus), plus a 10 kOhm NTC taped between two middle cells, into a 7-pin JST-XH in the
   order the drive board silkscreen shows. Check each tap with a meter: B1-B0, B2-B1, B3-B2,
   B4-B3 should each read one cell voltage.
5. Kapton over every strip and edge, 1 mm foam pad on top, slide the block into the box, lid
   on (six M3 into the deck inserts).
6. Connect the sense lead to the drive board BEFORE the power leads, so the BMS is awake when
   the pack is first connected.

## Why these parts

- Molicel P28A instead of P30B: same size, 35 A instead of 36 A, and it was in stock; the P30B
  was sold out at three stores on 2026-09-26.
- Upright cells: every series joint is on the top or bottom face, where the welder can reach.
  Lying the cells down would force end-to-end joints that cannot be welded after assembly.
- 3P rather than 2P: at 70 A each cell sees about 23 A instead of 35 A, so it runs cooler and
  keeps its voltage up under load.

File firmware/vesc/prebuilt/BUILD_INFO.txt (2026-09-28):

ATLAS-DRV-1 VESC firmware, built 2026-09-28T13:47Z
bldc:            https://github.com/vedderb/bldc.git @ 94b305ec124b67b0161f2d3d85c4d5b35e48edc5
bootloader:      https://github.com/vedderb/bldc-bootloader.git @ 2cdb167 (build_all/60_o_75_300_o_HD60_o_UAVC_OMEGA_o_75_300_R2_o_60_MK3_o_100_250_o_75_300_R3_o_60_MK4_o_60_MK5_o_HD75.bin)
hwconf sources:  firmware/vesc/hw_atlas_drv1.{c,h} @ 819164a
compiler:        arm-none-eabi-gcc (15:13.2.rel1-2) 13.2.1 20231009
extra flags:     -D__int64_t_defined=1
   text	   data	    bss	    dec	    hex	filename
 477384	   2332	 174936	 654652	  9fd3c	atlas_drv1.elf
74db9e90e5ba8b82746f9736c7e9cf9493d44440af3c79164762a0fac6295039  atlas_drv1.bin
d2c014d3b5faf843279d2b77325e128cace6d59ffa294fc0a7d68d96a57b0b33  vesc_bootloader.bin
bc0aa802825f9f787aad86d5e79b28ae292c7e77e4de323991ed1ece49db5540  atlas_drv1_full.hex

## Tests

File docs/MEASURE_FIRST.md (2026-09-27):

# Measure before printing or ordering

The chassis numbers in `mech/kit.py` come from car 1's plate and a keep-out model built from
Traxxas's specs and exploded views. Most are estimates. Each one below is a single parameter
in `kit.py` (`P = dict(...)`), and every script re-runs its checks when a number changes:
`python3 mech/kit.py` rebuilds all parts, repeats the interference test and rewrites the STLs.

Print `fit_coupon_front.stl` and `fit_coupon_rear.stl` first (about 20 g each). They are the
deck's tower saddles and body-post slots cut out of the full deck, so if they drop onto the
towers with the posts through the slots, the deck will too.

| # | measure | parameter | now | why it matters |
| --- | --- | --- | --- | --- |
| 1 | distance between the front and rear shock-tower top edges | `FRONT_TOWER_X`, `REAR_TOWER_X` | 168.3 / -141.7 (310 apart) | saddle positions; the rear one was moved 11.4 mm from car 1 using the wheelbase only |
| 2 | height of the tower top edges below where the deck will sit; old-plate underside to the chassis side-wall top | `TOWER_TOP_BELOW_OLD_PLATE`, `UNDER_CLEARANCE` | 16 / 45 | deck height; everything under the deck is checked against it |
| 3 | body-post positions on each tower (x and y at deck height) | `FRONT_POST`, `REAR_POST` | (180.4, +-38.6) / (-127.7, +-41.1) | the 24 mm post slots have +-8.5 mm of slack |
| 4 | tower thickness at the top | `TOWER_T` | 4 | saddle slot width (tower + 0.6) |
| 5 | battery bay: length, width, inner edge y, floor depth below the side-wall top | `BATT_BAY`, `TUB_DEPTH` | x -75..65, y 15..62, 24 deep | the pack box body is 124 x 44 x 72.4 mm (flange on top) and must fit, with 2.8 mm under it |
| 6 | stock battery hold-down posts: where they are and whether they come out | - | not modelled | they may have to be removed for the pack box |
| 7 | steering servo top (inverted case) and bellcrank sweep under the front of the deck | `SERVO`, `LINKAGE` | top at rim +25 / +12 | front rib and servo cable slot |
| 8 | transmission and motor tops under the rear of the deck | `GEARBOX`, `MOTOR_*` | rim +22 / +23 | rear ribs and the phase-wire slot |
| 9 | front tyre at full lock and full bump against the deck's front corners | `TYRE_*`, `BUMP`, `LOCK_DEG` | clears in the model | the nose taper starts at x 120 for this reason |
| 10 | Triton bottom face: spacing of the four corner M3 holes | `CAM_HOLE_PITCH` | 20 x 20, ESTIMATE | the cradle has +-1.5 mm slots; confirm on the camera (LUCID's manual says 4 corner M3 on the bottom but gives no spacing) |
| 11 | Puller Pro sensor plug: pitch and pin order | drive board J_HALL | JST-ZH 6-pin assumed | decides the board connector |
| 12 | M12 lidar plug bodies behind the TiM561 | `tim561()` estimates | 45 mm long | they run under the camera arch |
| 13 | wheel drop with the chassis lifted (suspension droop), front and rear | `STAND_H` in `mech/extras.py` | 40 mm assumed | the bench stand's height: 125 mm leaves about 13 mm under the tyres at 40 mm of droop |
| 14 | the camera cable's RJ45 plug and boot, width and height | `CAM_PLUG_NOTCH` in `kit.py` | 20 mm slot for a 14 x 10 mm boot | the slot through the right side pod; widen it for a fatter boot |
| 15 | antenna connectors on the M.2 Wi-Fi card from the dev kit | pigtails in `bom/make_bom.py` | MHF4 (AW-CB375NF datasheet); MHF4 pigtails ordered | check the card when the kit arrives |
| 16 | brain board corner H4 (brain-local 10, 5) under the camera RJ45 J6 | - | no screw from the top | the 20 mm standoff there only supports the board; the canopy uses the other three corners |

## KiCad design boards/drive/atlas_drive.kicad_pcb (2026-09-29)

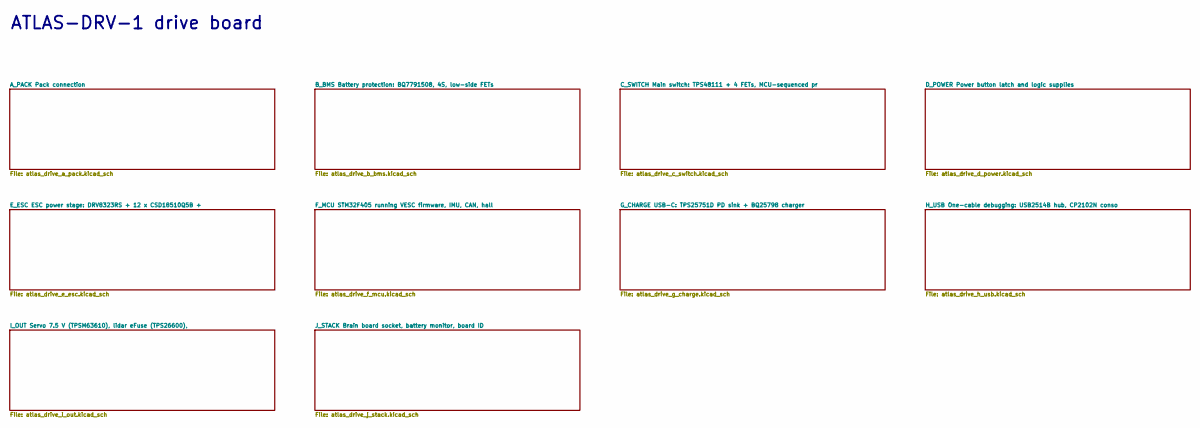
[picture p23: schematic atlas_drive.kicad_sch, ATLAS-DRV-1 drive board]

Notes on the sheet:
ATLAS-DRV-1 drive board

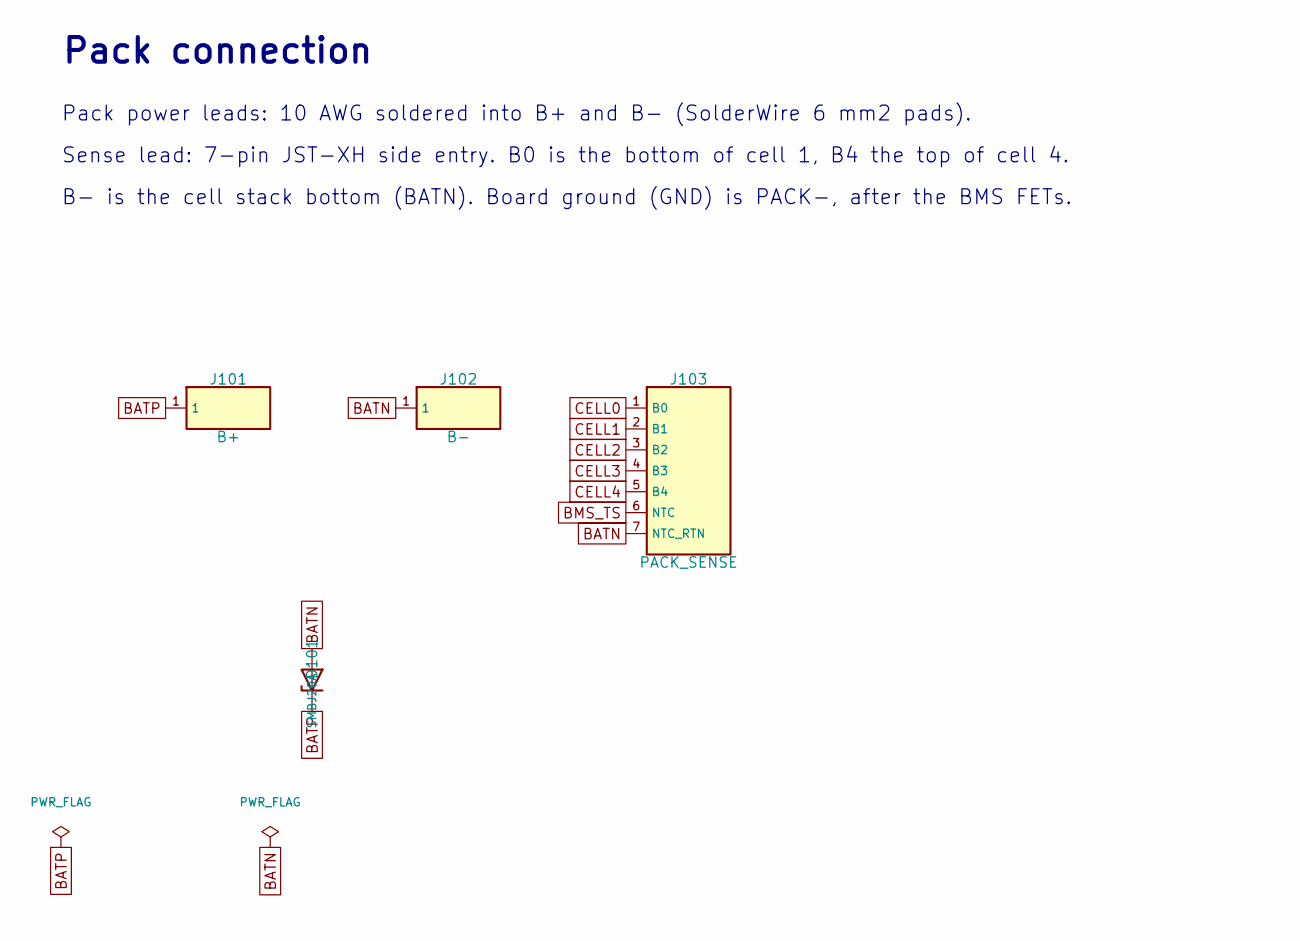
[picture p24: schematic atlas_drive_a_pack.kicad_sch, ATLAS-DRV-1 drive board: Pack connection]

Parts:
D101: SMBJ20A; D_SMB; MPN SMBJ20A
J101: B+; SolderWire-6sqmm_1x01_D3.5mm_OD7mm
J102: B-; SolderWire-6sqmm_1x01_D3.5mm_OD7mm
J103: PACK_SENSE; JST_XH_S7B-XH-A_1x07_P2.50mm_Horizontal; MPN S7B-XH-A(LF)(SN)

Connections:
BATN: D101.2 (A), J102.1, J103.7 (NTC_RTN); also elsewhere on the board
BATP: D101.1 (K), J101.1; also elsewhere on the board
BMS_TS: J103.6 (NTC); also elsewhere on the board
CELL0: J103.1 (B0); also elsewhere on the board
CELL1: J103.2 (B1); also elsewhere on the board
CELL2: J103.3 (B2); also elsewhere on the board
CELL3: J103.4 (B3); also elsewhere on the board
CELL4: J103.5 (B4); also elsewhere on the board

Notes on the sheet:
Pack connection
Pack power leads: 10 AWG soldered into B+ and B- (SolderWire 6 mm2 pads).
Sense lead: 7-pin JST-XH side entry. B0 is the bottom of cell 1, B4 the top of cell 4.
B- is the cell stack bottom (BATN). Board ground (GND) is PACK-, after the BMS FETs.

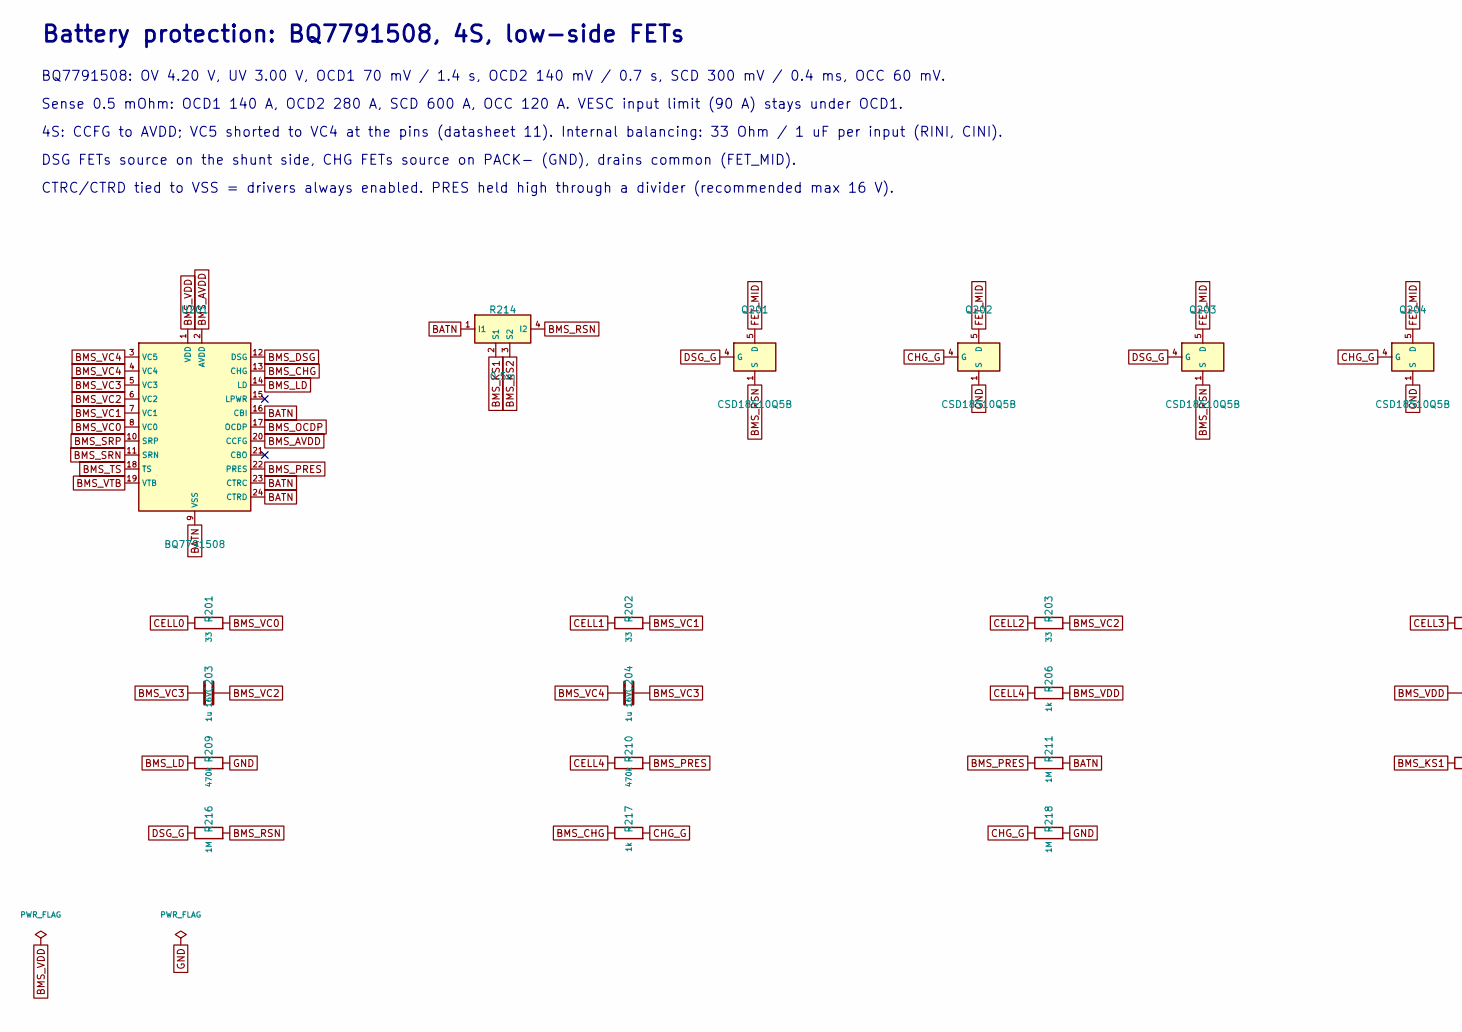
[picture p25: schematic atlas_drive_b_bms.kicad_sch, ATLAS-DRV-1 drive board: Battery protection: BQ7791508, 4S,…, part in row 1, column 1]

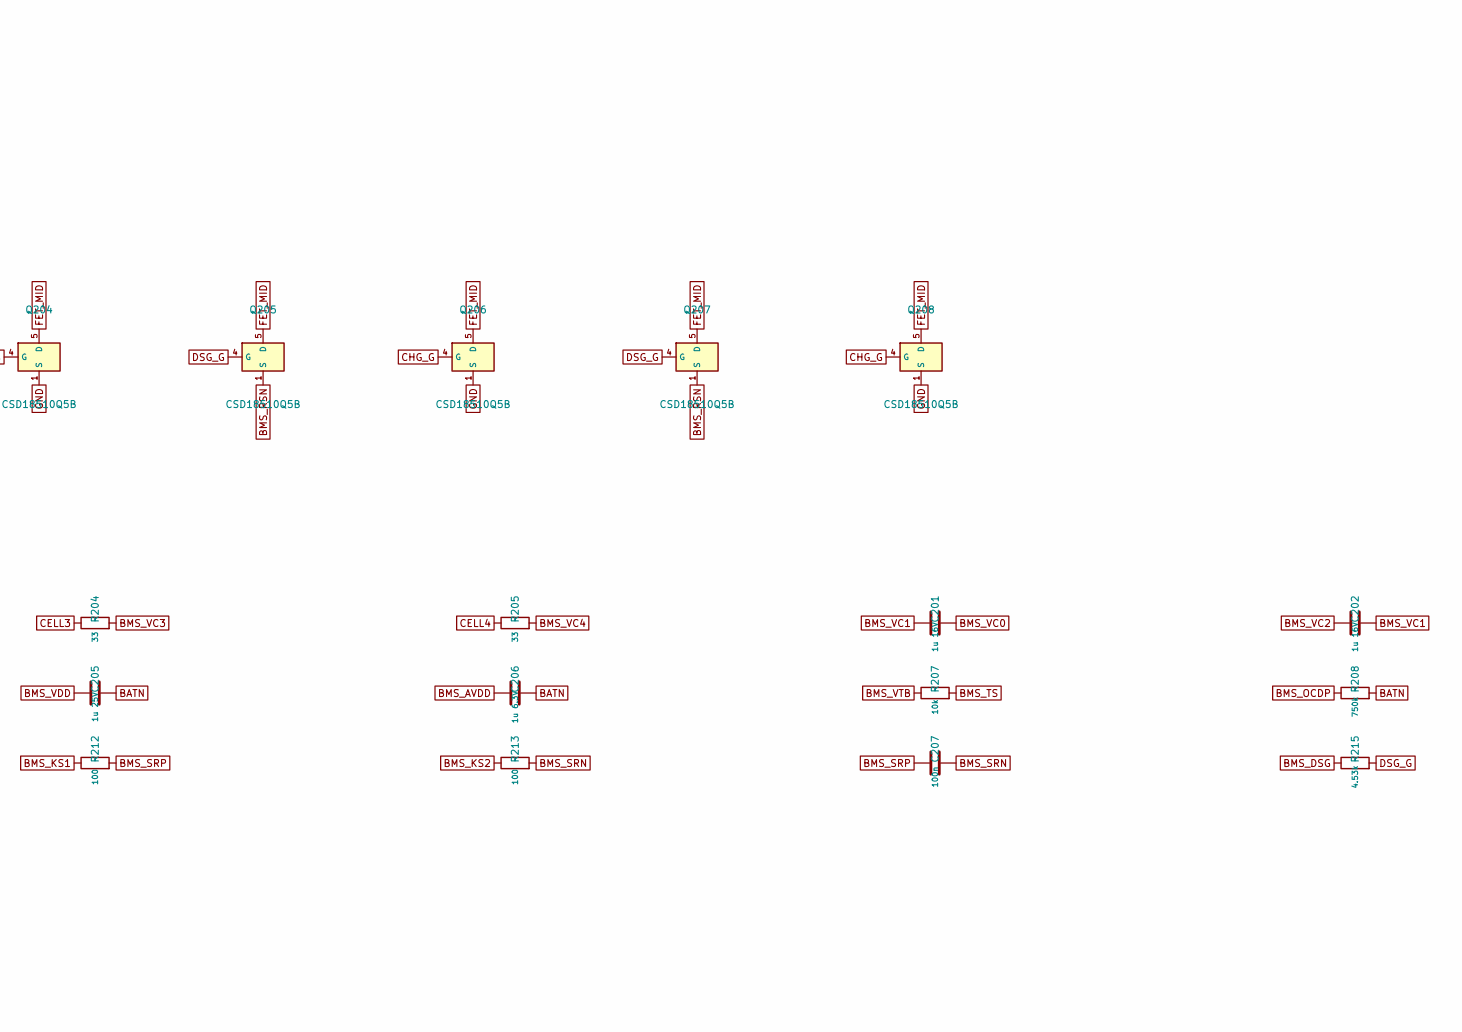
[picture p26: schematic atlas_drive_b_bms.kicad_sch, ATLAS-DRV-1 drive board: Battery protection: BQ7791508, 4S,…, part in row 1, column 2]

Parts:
C201, C202, C203, C204: 1u 16V; C_0603_1608Metric
C205: 1u 25V; C_0603_1608Metric
C206: 1u 6.3V; C_0402_1005Metric
C207: 100n; C_0402_1005Metric
Q201, Q202, Q203, Q204, Q205, Q206, Q207, Q208: CSD18510Q5B; TDSON-8-1; MPN CSD18510Q5B
R201, R202, R203, R204, R205: 33; R_0805_2012Metric
R206, R217: 1k; R_0402_1005Metric
R207: 10k; R_0402_1005Metric
R208: 750k; R_0402_1005Metric
R209, R210: 470k; R_0402_1005Metric
R211, R216, R218: 1M; R_0402_1005Metric
R212, R213: 100; R_0402_1005Metric
R214: 0.5m; R_Shunt_Isabellenhuette_BVR4026; MPN BVR-Z-R0005-1.0
R215: 4.53k; R_0402_1005Metric
U201: BQ7791508; TSSOP-24_4.4x7.8mm_P0.65mm; MPN BQ7791508PWR

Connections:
BATN: C205.2, C206.2, R208.2, R211.2, R214.1 (I1), U201.9 (VSS), U201.16 (CBI), U201.23 (CTRC), U201.24 (CTRD); also elsewhere on the board
BMS_AVDD: C206.1, U201.2 (AVDD), U201.20 (CCFG)
BMS_CHG: R217.1, U201.13 (CHG)
BMS_DSG: R215.1, U201.12 (DSG)
BMS_KS1: R212.1, R214.2 (S1); also elsewhere on the board
BMS_KS2: R213.1, R214.3 (S2); also elsewhere on the board
BMS_LD: R209.1, U201.14 (LD)
BMS_OCDP: R208.1, U201.17 (OCDP)
BMS_PRES: R210.2, R211.1, U201.22 (PRES)
BMS_RSN: Q201.1 (S), Q201.2 (S), Q201.3 (S), Q203.1 (S), Q203.2 (S), Q203.3 (S), Q205.1 (S), Q205.2 (S), Q205.3 (S), Q207.1 (S), Q207.2 (S), Q207.3 (S), R214.4 (I2), R216.2
BMS_SRN: C207.2, R213.2, U201.11 (SRN)
BMS_SRP: C207.1, R212.2, U201.10 (SRP)
BMS_TS: R207.2, U201.18 (TS); also elsewhere on the board
BMS_VC0: C201.2, R201.2, U201.8 (VC0)
BMS_VC1: C201.1, C202.2, R202.2, U201.7 (VC1)
BMS_VC2: C202.1, C203.2, R203.2, U201.6 (VC2)
BMS_VC3: C203.1, C204.2, R204.2, U201.5 (VC3)
BMS_VC4: C204.1, R205.2, U201.3 (VC5), U201.4 (VC4)
BMS_VDD: C205.1, R206.2, U201.1 (VDD)
BMS_VTB: R207.1, U201.19 (VTB)
CELL0: R201.1; also elsewhere on the board
CELL1: R202.1; also elsewhere on the board
CELL2: R203.1; also elsewhere on the board
CELL3: R204.1; also elsewhere on the board
CELL4: R205.1, R206.1, R210.1; also elsewhere on the board
CHG_G: Q202.4 (G), Q204.4 (G), Q206.4 (G), Q208.4 (G), R217.2, R218.1
DSG_G: Q201.4 (G), Q203.4 (G), Q205.4 (G), Q207.4 (G), R215.2, R216.1
FET_MID: Q201.5 (D), Q202.5 (D), Q203.5 (D), Q204.5 (D), Q205.5 (D), Q206.5 (D), Q207.5 (D), Q208.5 (D)
GND: Q202.1 (S), Q202.2 (S), Q202.3 (S), Q204.1 (S), Q204.2 (S), Q204.3 (S), Q206.1 (S), Q206.2 (S), Q206.3 (S), Q208.1 (S), Q208.2 (S), Q208.3 (S), R209.2, R218.2; also elsewhere on the board

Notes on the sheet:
Battery protection: BQ7791508, 4S, low-side FETs
BQ7791508: OV 4.20 V, UV 3.00 V, OCD1 70 mV / 1.4 s, OCD2 140 mV / 0.7 s, SCD 300 mV / 0.4 ms, OCC 60 mV.
Sense 0.5 mOhm: OCD1 140 A, OCD2 280 A, SCD 600 A, OCC 120 A. VESC input limit (90 A) stays under OCD1.
4S: CCFG to AVDD; VC5 shorted to VC4 at the pins (datasheet 11). Internal balancing: 33 Ohm / 1 uF per input (RINI, CINI).
DSG FETs source on the shunt side, CHG FETs source on PACK- (GND), drains common (FET_MID).
CTRC/CTRD tied to VSS = drivers always enabled. PRES held high through a divider (recommended max 16 V).

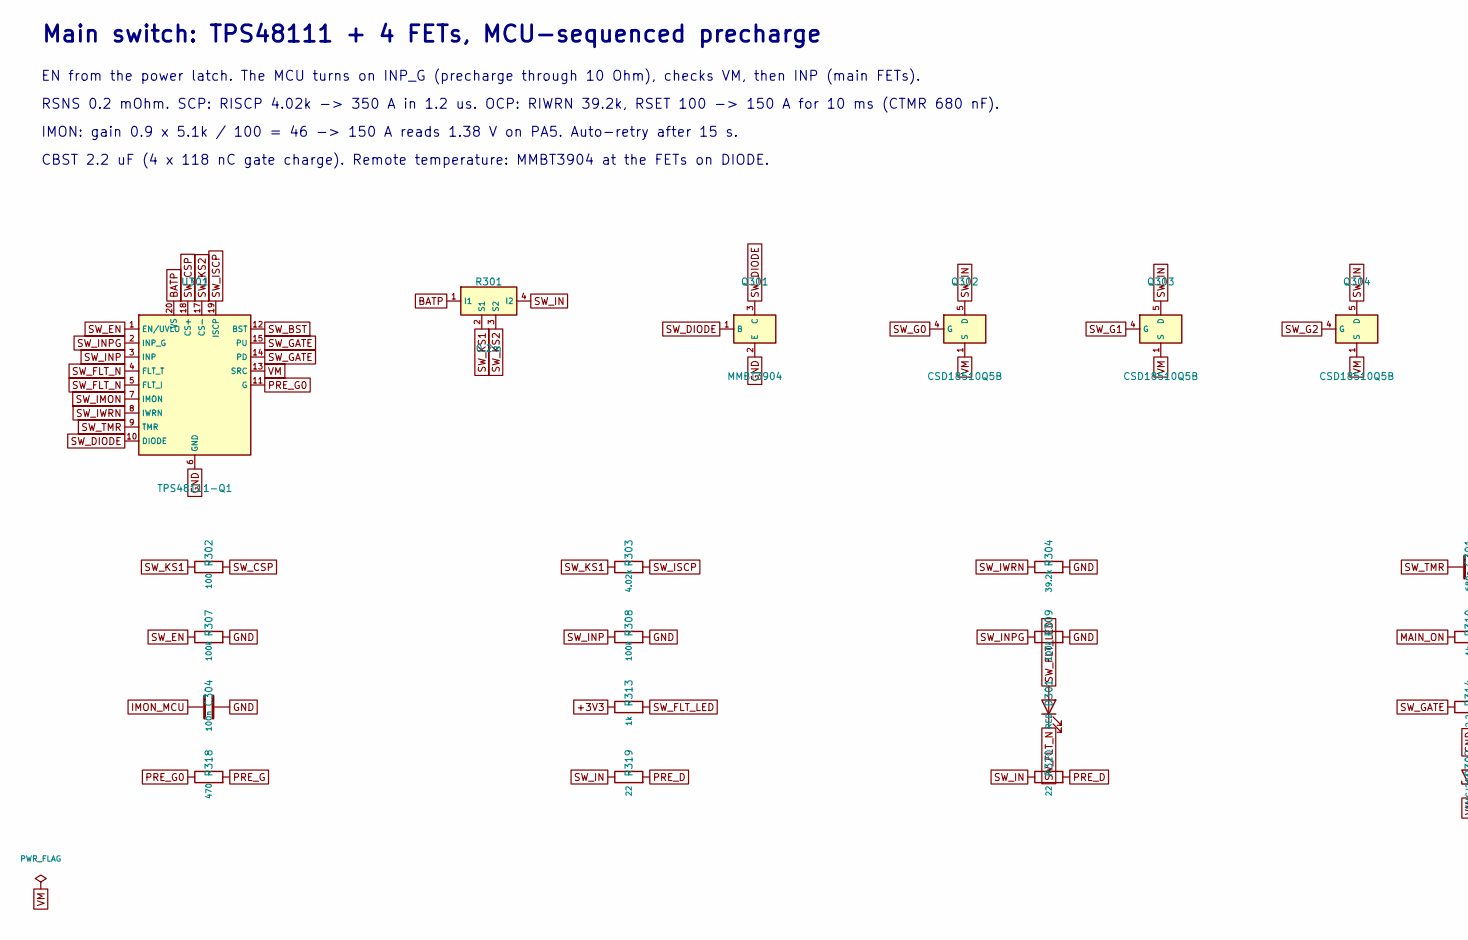
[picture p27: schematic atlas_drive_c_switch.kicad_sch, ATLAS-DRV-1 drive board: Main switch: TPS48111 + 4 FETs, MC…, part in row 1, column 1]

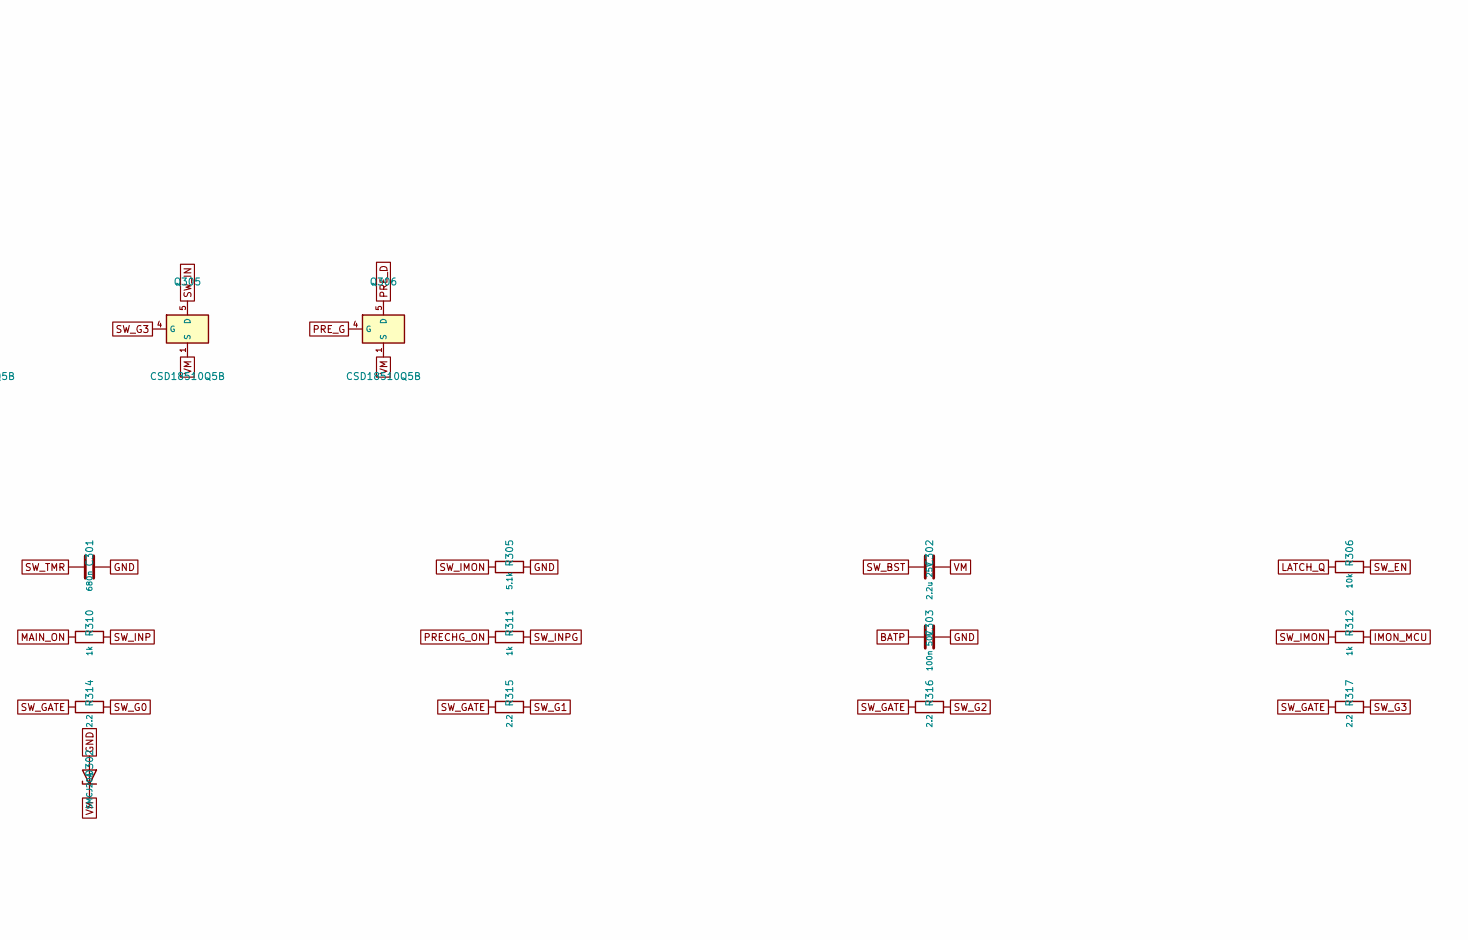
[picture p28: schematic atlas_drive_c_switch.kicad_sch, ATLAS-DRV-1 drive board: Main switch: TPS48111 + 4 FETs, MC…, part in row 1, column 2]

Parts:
C301: 680n; C_0402_1005Metric
C302: 2.2u 25V; C_0805_2012Metric
C303: 100n 50V; C_0402_1005Metric
C304: 100n; C_0402_1005Metric
D301: RED; LED_0603_1608Metric
D302: SMCJ20A; D_SMC; MPN SMCJ20A
Q301: MMBT3904; SOT-23; MPN MMBT3904LT1G
Q302, Q303, Q304, Q305, Q306: CSD18510Q5B; TDSON-8-1; MPN CSD18510Q5B
R301: 0.2m; R_Shunt_Isabellenhuette_BVR4026; MPN BVR-Z-R0002-1.0
R302: 100; R_0402_1005Metric
R303: 4.02k; R_0402_1005Metric
R304: 39.2k; R_0402_1005Metric
R305: 5.1k; R_0402_1005Metric
R306: 10k; R_0402_1005Metric
R307, R308, R309: 100k; R_0402_1005Metric
R310, R311, R312, R313: 1k; R_0402_1005Metric
R314, R315, R316, R317: 2.2; R_0402_1005Metric
R318: 470; R_0402_1005Metric
R319, R320: 22; R_2512_6332Metric; MPN CRCW251222R0FKEGHP
U301: TPS48111-Q1; TI_DGX0019A_VSSOP-19_3x5.1mm_P0.5mm; MPN TPS48111QDGXRQ1

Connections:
+3V3: R313.1; also elsewhere on the board
BATP: C303.1, R301.1 (I1), U301.20 (VS); also elsewhere on the board
GND: C301.2, C303.2, C304.2, D302.2 (A), Q301.2 (E), R304.2, R305.2, R307.2, R308.2, R309.2, U301.6 (GND); also elsewhere on the board
IMON_MCU: C304.1, R312.2; also elsewhere on the board
LATCH_Q: R306.1; also elsewhere on the board
MAIN_ON: R310.1; also elsewhere on the board
PRECHG_ON: R311.1; also elsewhere on the board
PRE_D: Q306.5 (D), R319.2, R320.2
PRE_G: Q306.4 (G), R318.2
PRE_G0: R318.1, U301.11 (G)
SW_BST: C302.1, U301.12 (BST)
SW_CSP: R302.2, U301.18 (CS+)
SW_DIODE: Q301.1 (B), Q301.3 (C), U301.10 (DIODE)
SW_EN: R306.2, R307.1, U301.1 (EN/UVLO)
SW_FLT_LED: D301.2 (A), R313.2
SW_FLT_N: D301.1 (K), U301.4 (FLT_T), U301.5 (FLT_I)
SW_G0: Q302.4 (G), R314.2
SW_G1: Q303.4 (G), R315.2
SW_G2: Q304.4 (G), R316.2
SW_G3: Q305.4 (G), R317.2
SW_GATE: R314.1, R315.1, R316.1, R317.1, U301.14 (PD), U301.15 (PU)
SW_IMON: R305.1, R312.1, U301.7 (IMON)
SW_IN: Q302.5 (D), Q303.5 (D), Q304.5 (D), Q305.5 (D), R301.4 (I2), R319.1, R320.1
SW_INP: R308.1, R310.2, U301.3 (INP)
SW_INPG: R309.1, R311.2, U301.2 (INP_G)
SW_ISCP: R303.2, U301.19 (ISCP)
SW_IWRN: R304.1, U301.8 (IWRN)
SW_KS1: R301.2 (S1), R302.1, R303.1
SW_KS2: R301.3 (S2), U301.17 (CS-)
SW_TMR: C301.1, U301.9 (TMR)
VM: C302.2, D302.1 (K), Q302.1 (S), Q302.2 (S), Q302.3 (S), Q303.1 (S), Q303.2 (S), Q303.3 (S), Q304.1 (S), Q304.2 (S), Q304.3 (S), Q305.1 (S), Q305.2 (S), Q305.3 (S), Q306.1 (S), Q306.2 (S), Q306.3 (S), U301.13 (SRC); also elsewhere on the board

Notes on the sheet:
Main switch: TPS48111 + 4 FETs, MCU-sequenced precharge
EN from the power latch. The MCU turns on INP_G (precharge through 10 Ohm), checks VM, then INP (main FETs).
RSNS 0.2 mOhm. SCP: RISCP 4.02k -> 350 A in 1.2 us. OCP: RIWRN 39.2k, RSET 100 -> 150 A for 10 ms (CTMR 680 nF).
IMON: gain 0.9 x 5.1k / 100 = 46 -> 150 A reads 1.38 V on PA5. Auto-retry after 15 s.
CBST 2.2 uF (4 x 118 nC gate charge). Remote temperature: MMBT3904 at the FETs on DIODE.

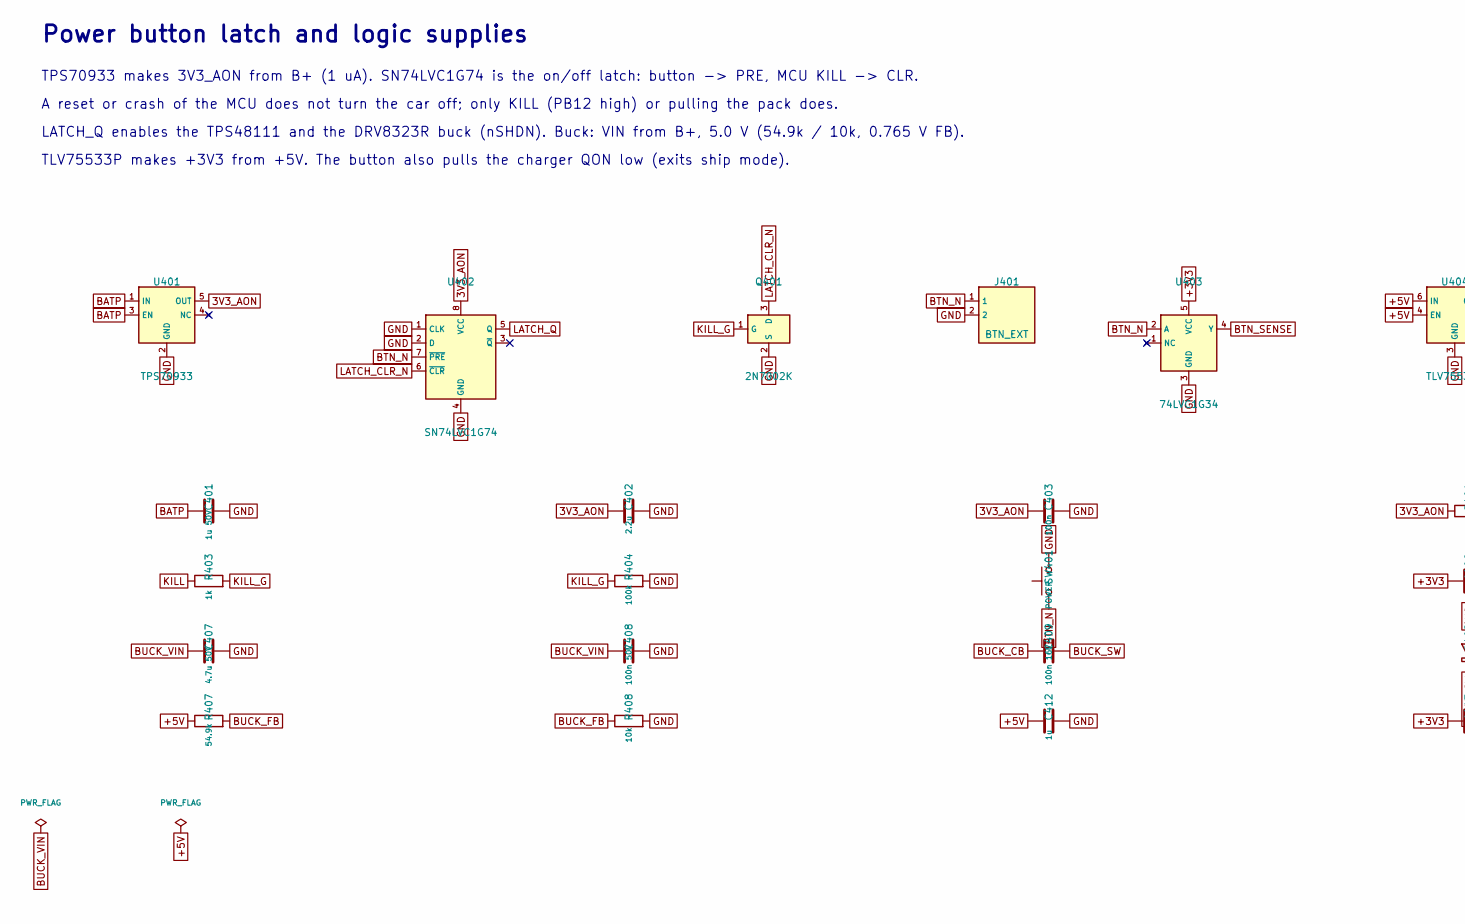
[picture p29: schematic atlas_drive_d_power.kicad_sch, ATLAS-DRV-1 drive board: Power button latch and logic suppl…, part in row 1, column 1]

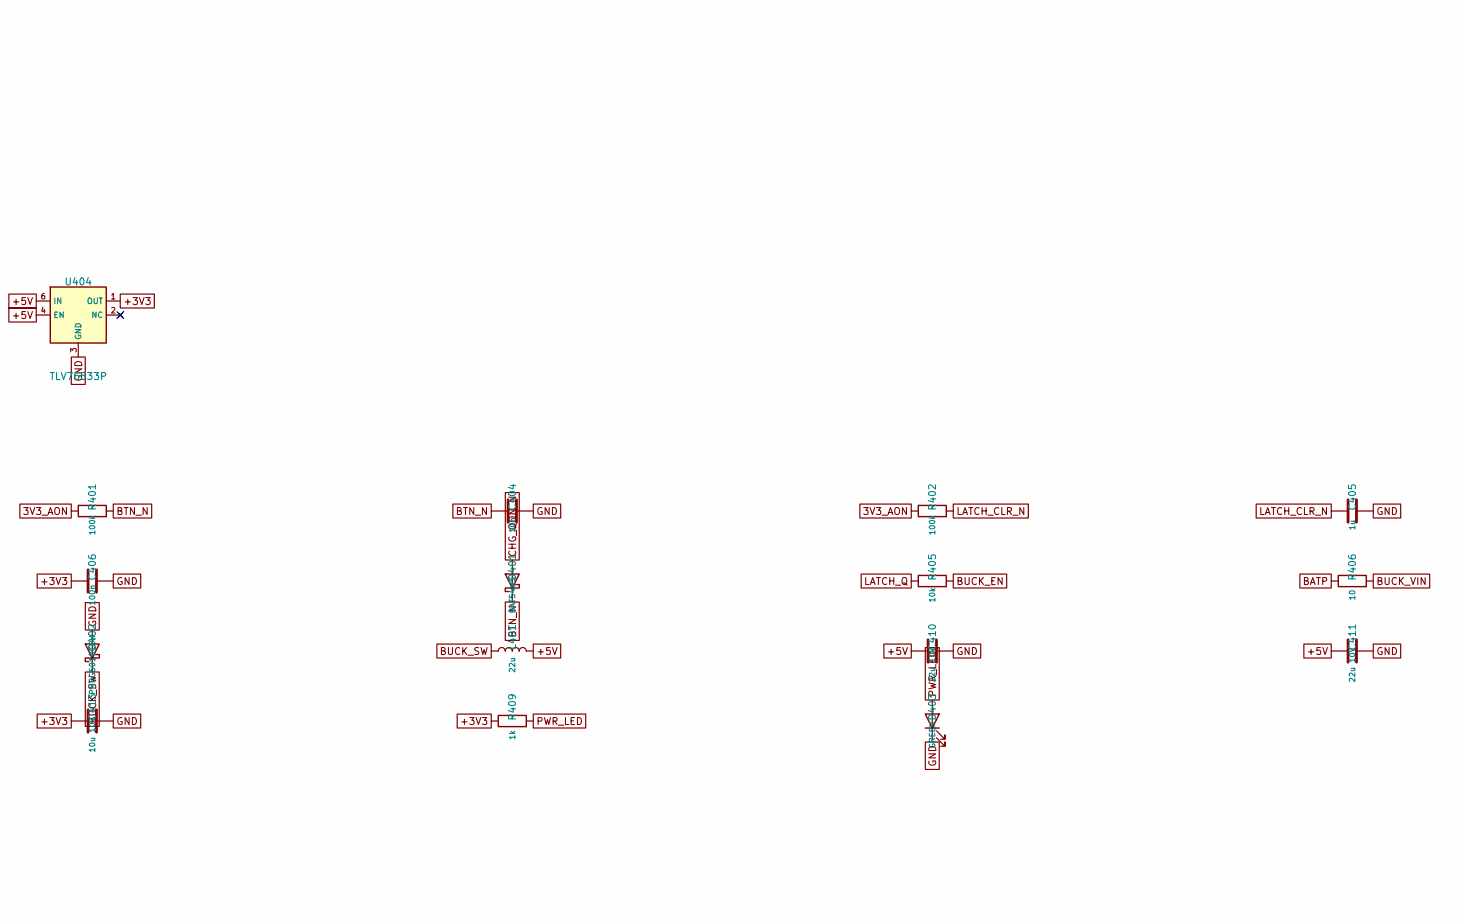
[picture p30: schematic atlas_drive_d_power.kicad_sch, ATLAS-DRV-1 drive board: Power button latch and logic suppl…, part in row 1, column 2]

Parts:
C401: 1u 50V; C_0603_1608Metric
C402: 2.2u; C_0603_1608Metric
C403, C406: 100n; C_0402_1005Metric
C404: 10n; C_0402_1005Metric
C405, C412: 1u; C_0603_1608Metric
C407: 4.7u 50V; C_1206_3216Metric
C408: 100n 50V; C_0402_1005Metric
C409: 100n 16V; C_0402_1005Metric
C410, C411: 22u 10V; C_0805_2012Metric
C413: 10u 10V; C_0805_2012Metric
D401: BAT54WS; D_SOD-323; MPN BAT54WS
D402: PMEG6010CEH; D_SOD-123F; MPN PMEG6010CEH
D403: GREEN; LED_0603_1608Metric
J401: BTN_EXT; JST_PH_S2B-PH-K_1x02_P2.00mm_Horizontal; MPN S2B-PH-K-S(LF)(SN)
L401: 22u; L_Bourns-SRN4018; MPN SRN4018-220M
Q401: 2N7002K; SOT-23; MPN 2N7002K
R401, R402, R404: 100k; R_0402_1005Metric
R403, R409: 1k; R_0402_1005Metric
R405, R408: 10k; R_0402_1005Metric
R406: 10; R_0603_1608Metric
R407: 54.9k; R_0402_1005Metric
SW401: POWER; SW_Push_1P1T_NO_CK_KMR2; MPN KMR211NG LFS
U401: TPS70933; SOT-23-5; MPN TPS70933DBVR
U402: SN74LVC1G74; VSSOP-8_2.3x2mm_P0.5mm; MPN SN74LVC1G74DCUR
U403: 74LVC1G34; SOT-353_SC-70-5; MPN SN74LVC1G34DCKR
U404: TLV75533P; WSON-6-1EP_2x2mm_P0.65mm_EP1x1.6mm; MPN TLV75533PDRVR

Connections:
3V3_AON: C402.1, C403.1, R401.1, R402.1, U401.5 (OUT), U402.8 (VCC); also elsewhere on the board
+3V3: C406.1, C413.1, R409.1, U403.5 (VCC), U404.1 (OUT); also elsewhere on the board
+5V: C410.1, C411.1, C412.1, L401.2, R407.1, U404.4 (EN), U404.6 (IN); also elsewhere on the board
BATP: C401.1, R406.1, U401.1 (IN), U401.3 (EN); also elsewhere on the board
BTN_N: C404.1, D401.1 (K), J401.1, R401.2, SW401.1, U402.7 (~PRE), U403.2 (A)
BTN_SENSE: U403.4 (Y); also elsewhere on the board
BUCK_CB: C409.1; also elsewhere on the board
BUCK_EN: R405.2; also elsewhere on the board
BUCK_FB: R407.2, R408.1; also elsewhere on the board
BUCK_SW: C409.2, D402.1 (K), L401.1; also elsewhere on the board
BUCK_VIN: C407.1, C408.1, R406.2; also elsewhere on the board
CHG_QON_N: D401.2 (A); also elsewhere on the board
GND: C401.2, C402.2, C403.2, C404.2, C405.2, C406.2, C407.2, C408.2, C410.2, C411.2, C412.2, C413.2, D402.2 (A), D403.1 (K), J401.2, Q401.2 (S), R404.2, R408.2, SW401.2, U401.2 (GND), U402.1 (CLK), U402.2 (D), U402.4 (GND), U403.3 (GND), U404.3 (GND), U404.7 (GND); also elsewhere on the board
KILL: R403.1; also elsewhere on the board
KILL_G: Q401.1 (G), R403.2, R404.1
LATCH_CLR_N: C405.1, Q401.3 (D), R402.2, U402.6 (~CLR)
LATCH_Q: R405.1, U402.5 (Q); also elsewhere on the board
PWR_LED: D403.2 (A), R409.2

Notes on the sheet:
Power button latch and logic supplies
TPS70933 makes 3V3_AON from B+ (1 uA). SN74LVC1G74 is the on/off latch: button -> PRE, MCU KILL -> CLR.
A reset or crash of the MCU does not turn the car off; only KILL (PB12 high) or pulling the pack does.
LATCH_Q enables the TPS48111 and the DRV8323R buck (nSHDN). Buck: VIN from B+, 5.0 V (54.9k / 10k, 0.765 V FB).
TLV75533P makes +3V3 from +5V. The button also pulls the charger QON low (exits ship mode).

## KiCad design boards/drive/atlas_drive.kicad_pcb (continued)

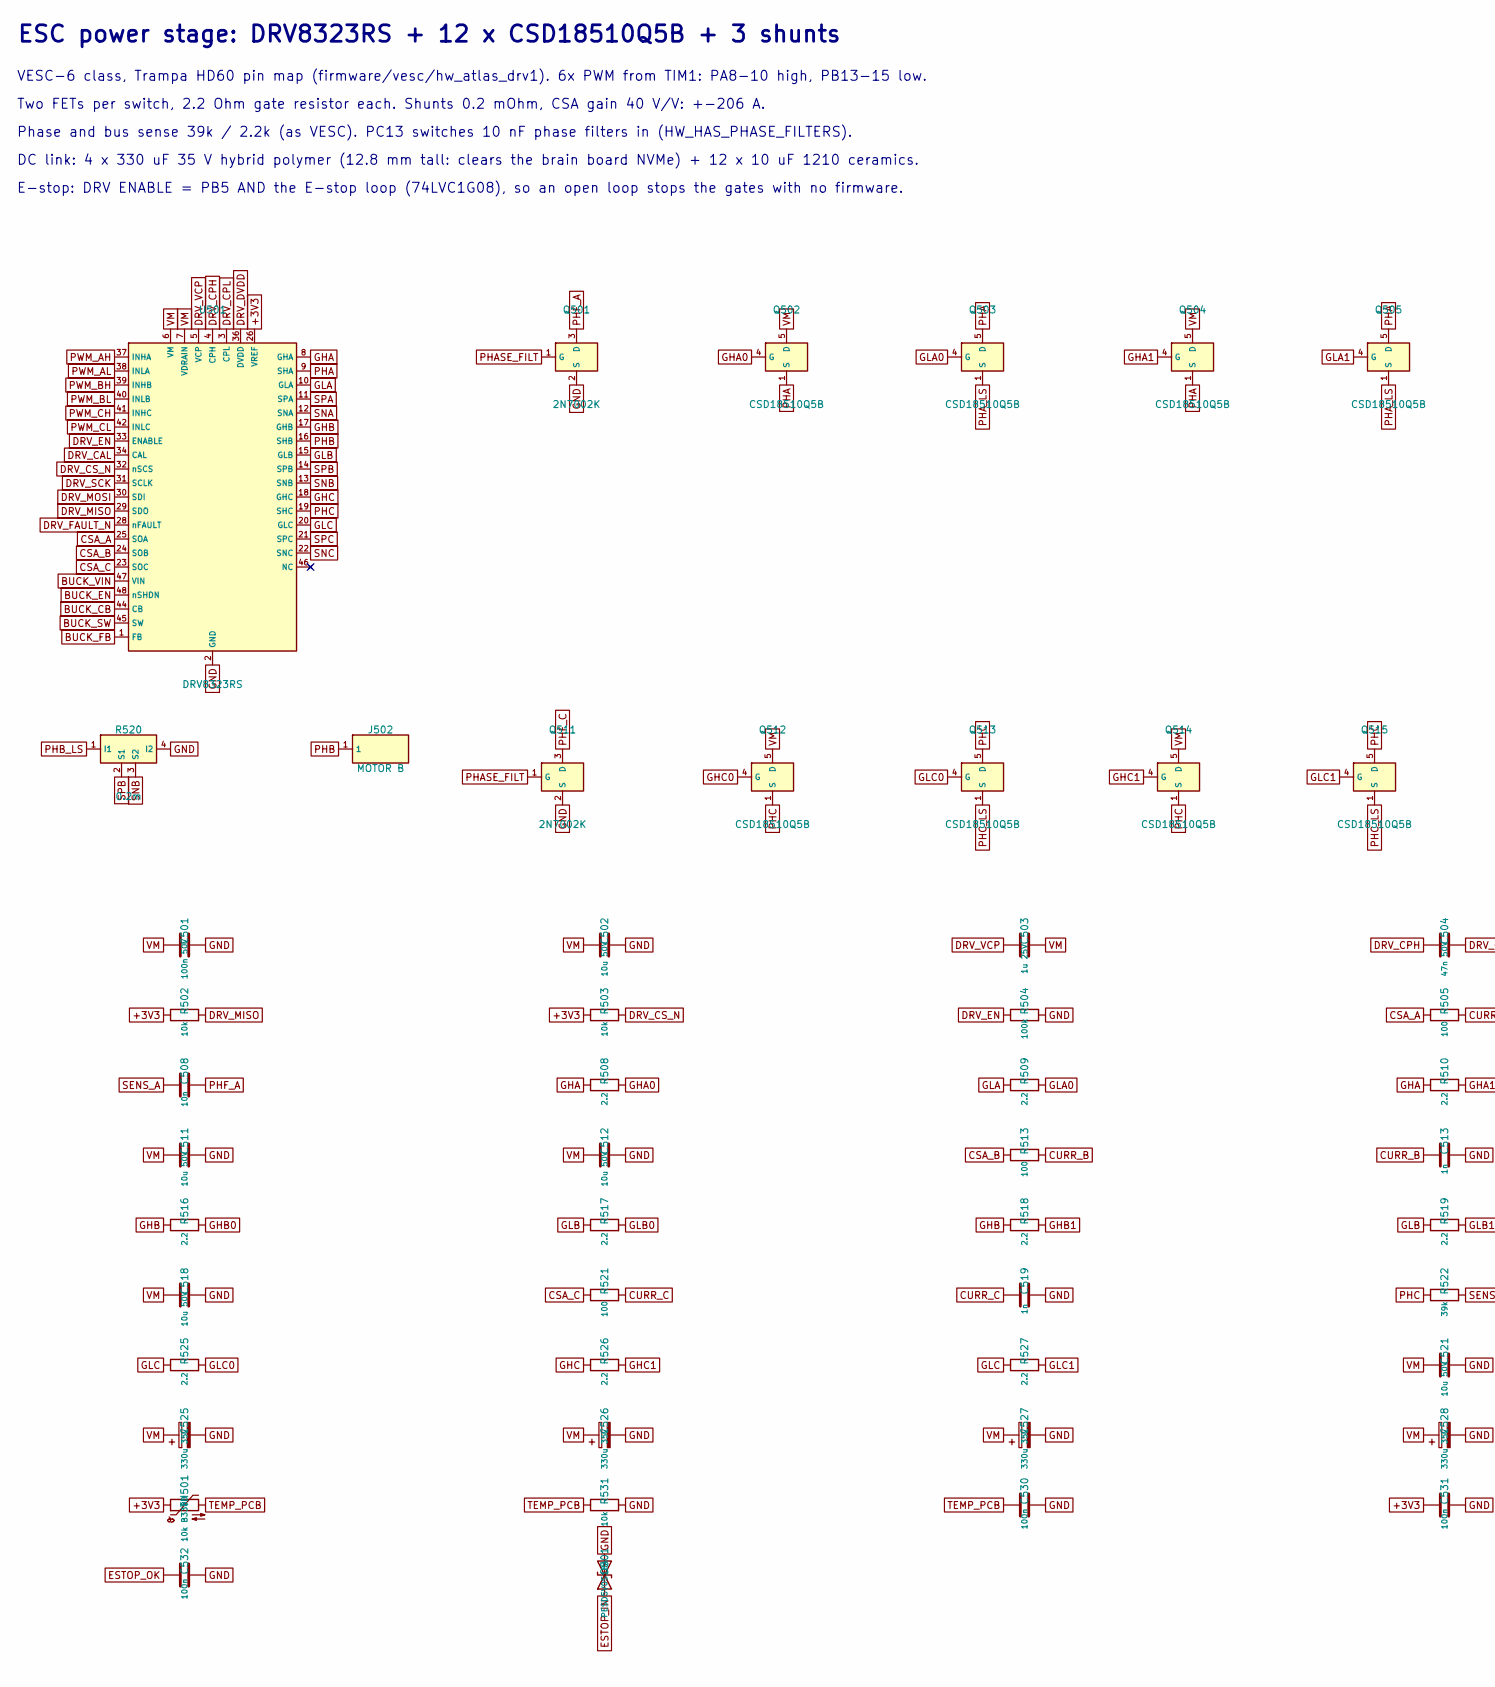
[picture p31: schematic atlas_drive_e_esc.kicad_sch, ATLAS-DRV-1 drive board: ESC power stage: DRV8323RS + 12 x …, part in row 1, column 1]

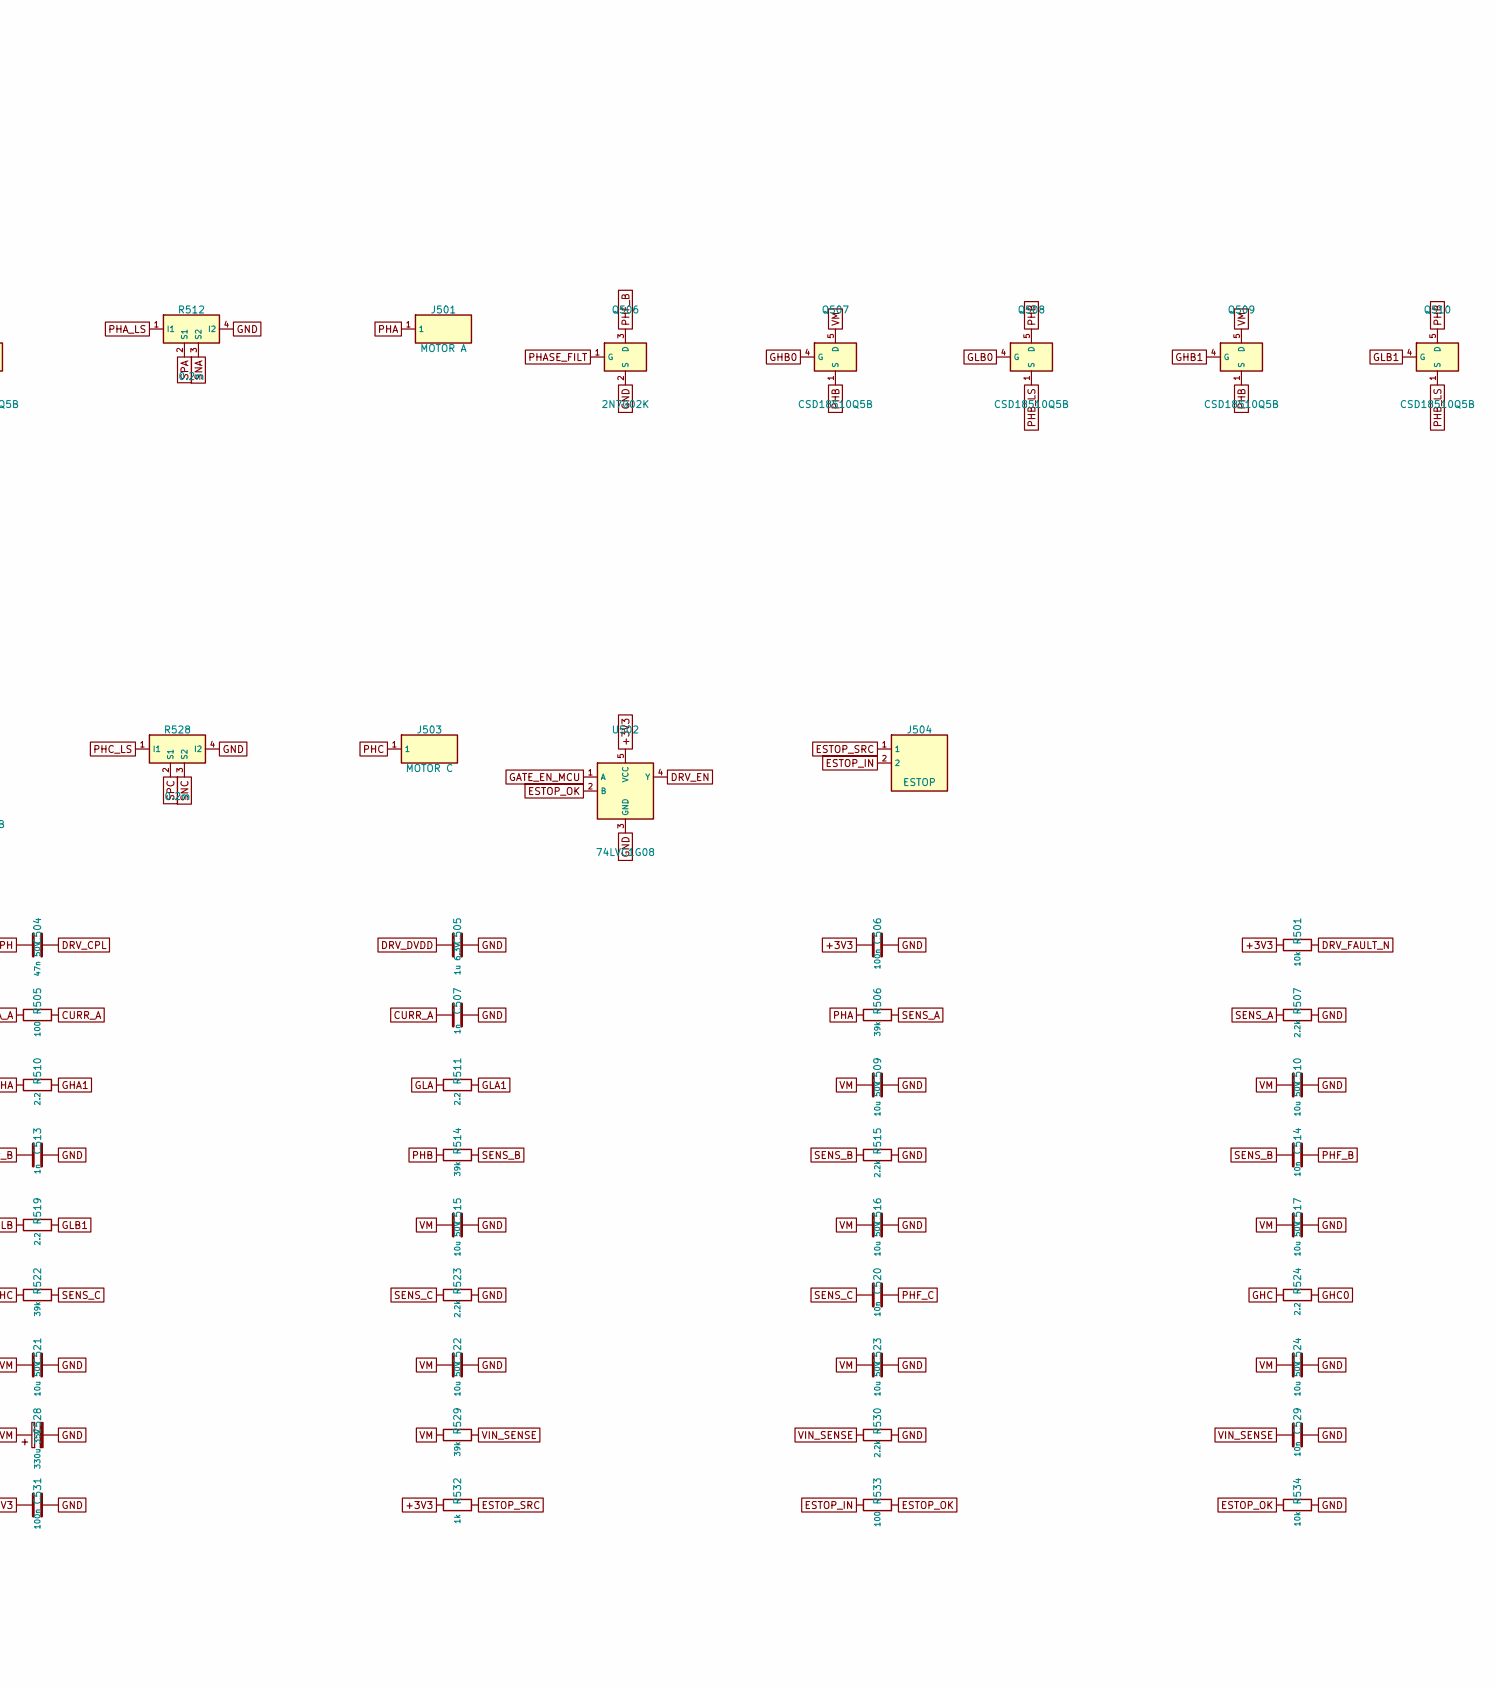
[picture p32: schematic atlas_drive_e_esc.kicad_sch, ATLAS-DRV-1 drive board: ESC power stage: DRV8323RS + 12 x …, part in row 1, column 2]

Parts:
C501: 100n 50V; C_0402_1005Metric
C502, C509, C510, C511, C512, C515, C516, C517, C518, C521, C522, C523, C524: 10u 50V; C_1210_3225Metric; MPN GRM32ER71H106KA12L
C503: 1u 25V; C_0603_1608Metric
C504: 47n 50V; C_0603_1608Metric
C505: 1u 6.3V; C_0402_1005Metric
C506, C530, C531, C532: 100n; C_0402_1005Metric
C507, C513, C519: 1n; C_0402_1005Metric
C508, C514, C520, C529: 10n; C_0402_1005Metric
C525, C526, C527, C528: 330u 35V; CP_Elec_10x10; MPN EEH-ZU1V331P
D501: PESD5V0S1BA; D_SOD-323; MPN PESD5V0S1BA
J501: MOTOR A; WirePad_SMD_9x7mm_10Vias
J502: MOTOR B; WirePad_SMD_9x7mm_10Vias
J503: MOTOR C; WirePad_SMD_9x7mm_10Vias
J504: ESTOP; JST_PH_B2B-PH-K_1x02_P2.00mm_Vertical; MPN B2B-PH-K-S(LF)(SN)
Q501, Q506, Q511: 2N7002K; SOT-23; MPN 2N7002K
Q502, Q503, Q504, Q505, Q507, Q508, Q509, Q510, Q512, Q513, Q514, Q515: CSD18510Q5B; TDSON-8-1; MPN CSD18510Q5B
R501, R502, R503, R531, R534: 10k; R_0402_1005Metric
R504: 100k; R_0402_1005Metric
R505, R513, R521, R533: 100; R_0402_1005Metric
R506, R514, R522, R529: 39k; R_0402_1005Metric
R507, R515, R523, R530: 2.2k; R_0402_1005Metric
R508, R509, R510, R511, R516, R517, R518, R519, R524, R525, R526, R527: 2.2; R_0402_1005Metric
R512, R520, R528: 0.2m; R_Shunt_Isabellenhuette_BVR4026; MPN BVR-Z-R0002-1.0
R532: 1k; R_0402_1005Metric
TH501: 10k B3380; R_0402_1005Metric; MPN NCP15XH103F03RC
U501: DRV8323RS; Texas_RGZ0048A_VQFN-48-1EP_7x7mm_P0.5mm_EP5.15x5.15mm_Therm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; MPN DRV8323RSRGZR
U502: 74LVC1G08; SOT-353_SC-70-5; MPN SN74LVC1G08DCKR

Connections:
+3V3: C506.1, C531.1, R501.1, R502.1, R503.1, R532.1, TH501.1, U501.26 (VREF), U502.5 (VCC); also elsewhere on the board
BUCK_CB: U501.44 (CB); also elsewhere on the board
BUCK_EN: U501.48 (nSHDN); also elsewhere on the board
BUCK_FB: U501.1 (FB); also elsewhere on the board
BUCK_SW: U501.45 (SW); also elsewhere on the board
BUCK_VIN: U501.47 (VIN); also elsewhere on the board
CSA_A: R505.1, U501.25 (SOA)
CSA_B: R513.1, U501.24 (SOB)
CSA_C: R521.1, U501.23 (SOC)
CURR_A: C507.1, R505.2; also elsewhere on the board
CURR_B: C513.1, R513.2; also elsewhere on the board
CURR_C: C519.1, R521.2; also elsewhere on the board
DRV_CAL: U501.34 (CAL); also elsewhere on the board
DRV_CPH: C504.1, U501.4 (CPH)
DRV_CPL: C504.2, U501.3 (CPL)
DRV_CS_N: R503.2, U501.32 (nSCS); also elsewhere on the board
DRV_DVDD: C505.1, U501.36 (DVDD)
DRV_EN: R504.1, U501.33 (ENABLE), U502.4 (Y)
DRV_FAULT_N: R501.2, U501.28 (nFAULT); also elsewhere on the board
DRV_MISO: R502.2, U501.29 (SDO); also elsewhere on the board
DRV_MOSI: U501.30 (SDI); also elsewhere on the board
DRV_SCK: U501.31 (SCLK); also elsewhere on the board
DRV_VCP: C503.1, U501.5 (VCP)
ESTOP_IN: D501.1 (A1), J504.2, R533.1
ESTOP_OK: C532.1, R533.2, R534.1, U502.2 (B); also elsewhere on the board
ESTOP_SRC: J504.1, R532.2
GATE_EN_MCU: U502.1 (A); also elsewhere on the board
GHA: R508.1, R510.1, U501.8 (GHA)
GHA0: Q502.4 (G), R508.2
GHA1: Q504.4 (G), R510.2
GHB: R516.1, R518.1, U501.17 (GHB)
GHB0: Q507.4 (G), R516.2
GHB1: Q509.4 (G), R518.2
GHC: R524.1, R526.1, U501.18 (GHC)
GHC0: Q512.4 (G), R524.2
GHC1: Q514.4 (G), R526.2
GLA: R509.1, R511.1, U501.10 (GLA)
GLA0: Q503.4 (G), R509.2
GLA1: Q505.4 (G), R511.2
GLB: R517.1, R519.1, U501.15 (GLB)
GLB0: Q508.4 (G), R517.2
GLB1: Q510.4 (G), R519.2
GLC: R525.1, R527.1, U501.20 (GLC)
GLC0: Q513.4 (G), R525.2
GLC1: Q515.4 (G), R527.2
GND: C501.2, C502.2, C505.2, C506.2, C507.2, C509.2, C510.2, C511.2, C512.2, C513.2, C515.2, C516.2, C517.2, C518.2, C519.2, C521.2, C522.2, C523.2, C524.2, C525.2, C526.2, C527.2, C528.2, C529.2, C530.2, C531.2, C532.2, D501.2 (A2), Q501.2 (S), Q506.2 (S), Q511.2 (S), R504.2, R507.2, R512.4 (I2), R515.2, R520.4 (I2), R523.2, R528.4 (I2), R530.2, R531.2, R534.2, U501.2 (GND), U501.27 (GND), U501.35 (GND), U501.43 (GND), U501.49 (GND), U502.3 (GND); also elsewhere on the board
PHA: J501.1, Q502.1 (S), Q502.2 (S), Q502.3 (S), Q503.5 (D), Q504.1 (S), Q504.2 (S), Q504.3 (S), Q505.5 (D), R506.1, U501.9 (SHA)
PHASE_FILT: Q501.1 (G), Q506.1 (G), Q511.1 (G); also elsewhere on the board
PHA_LS: Q503.1 (S), Q503.2 (S), Q503.3 (S), Q505.1 (S), Q505.2 (S), Q505.3 (S), R512.1 (I1)
PHB: J502.1, Q507.1 (S), Q507.2 (S), Q507.3 (S), Q508.5 (D), Q509.1 (S), Q509.2 (S), Q509.3 (S), Q510.5 (D), R514.1, U501.16 (SHB)
PHB_LS: Q508.1 (S), Q508.2 (S), Q508.3 (S), Q510.1 (S), Q510.2 (S), Q510.3 (S), R520.1 (I1)
PHC: J503.1, Q512.1 (S), Q512.2 (S), Q512.3 (S), Q513.5 (D), Q514.1 (S), Q514.2 (S), Q514.3 (S), Q515.5 (D), R522.1, U501.19 (SHC)
PHC_LS: Q513.1 (S), Q513.2 (S), Q513.3 (S), Q515.1 (S), Q515.2 (S), Q515.3 (S), R528.1 (I1)
PHF_A: C508.2, Q501.3 (D)
PHF_B: C514.2, Q506.3 (D)
PHF_C: C520.2, Q511.3 (D)
PWM_AH: U501.37 (INHA); also elsewhere on the board
PWM_AL: U501.38 (INLA); also elsewhere on the board
PWM_BH: U501.39 (INHB); also elsewhere on the board
PWM_BL: U501.40 (INLB); also elsewhere on the board
PWM_CH: U501.41 (INHC); also elsewhere on the board
PWM_CL: U501.42 (INLC); also elsewhere on the board
SENS_A: C508.1, R506.2, R507.1; also elsewhere on the board
SENS_B: C514.1, R514.2, R515.1; also elsewhere on the board
SENS_C: C520.1, R522.2, R523.1; also elsewhere on the board
SNA: R512.3 (S2), U501.12 (SNA)
SNB: R520.3 (S2), U501.13 (SNB)
SNC: R528.3 (S2), U501.22 (SNC)
SPA: R512.2 (S1), U501.11 (SPA)
SPB: R520.2 (S1), U501.14 (SPB)
SPC: R528.2 (S1), U501.21 (SPC)
TEMP_PCB: C530.1, R531.1, TH501.2; also elsewhere on the board
VIN_SENSE: C529.1, R529.2, R530.1; also elsewhere on the board
VM: C501.1, C502.1, C503.2, C509.1, C510.1, C511.1, C512.1, C515.1, C516.1, C517.1, C518.1, C521.1, C522.1, C523.1, C524.1, C525.1, C526.1, C527.1, C528.1, Q502.5 (D), Q504.5 (D), Q507.5 (D), Q509.5 (D), Q512.5 (D), Q514.5 (D), R529.1, U501.6 (VM), U501.7 (VDRAIN); also elsewhere on the board

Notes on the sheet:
ESC power stage: DRV8323RS + 12 x CSD18510Q5B + 3 shunts
VESC-6 class, Trampa HD60 pin map (firmware/vesc/hw_atlas_drv1). 6x PWM from TIM1: PA8-10 high, PB13-15 low.
Two FETs per switch, 2.2 Ohm gate resistor each. Shunts 0.2 mOhm, CSA gain 40 V/V: +-206 A.
Phase and bus sense 39k / 2.2k (as VESC). PC13 switches 10 nF phase filters in (HW_HAS_PHASE_FILTERS).
DC link: 4 x 330 uF 35 V hybrid polymer (12.8 mm tall: clears the brain board NVMe) + 12 x 10 uF 1210 ceramics.
E-stop: DRV ENABLE = PB5 AND the E-stop loop (74LVC1G08), so an open loop stops the gates with no firmware.

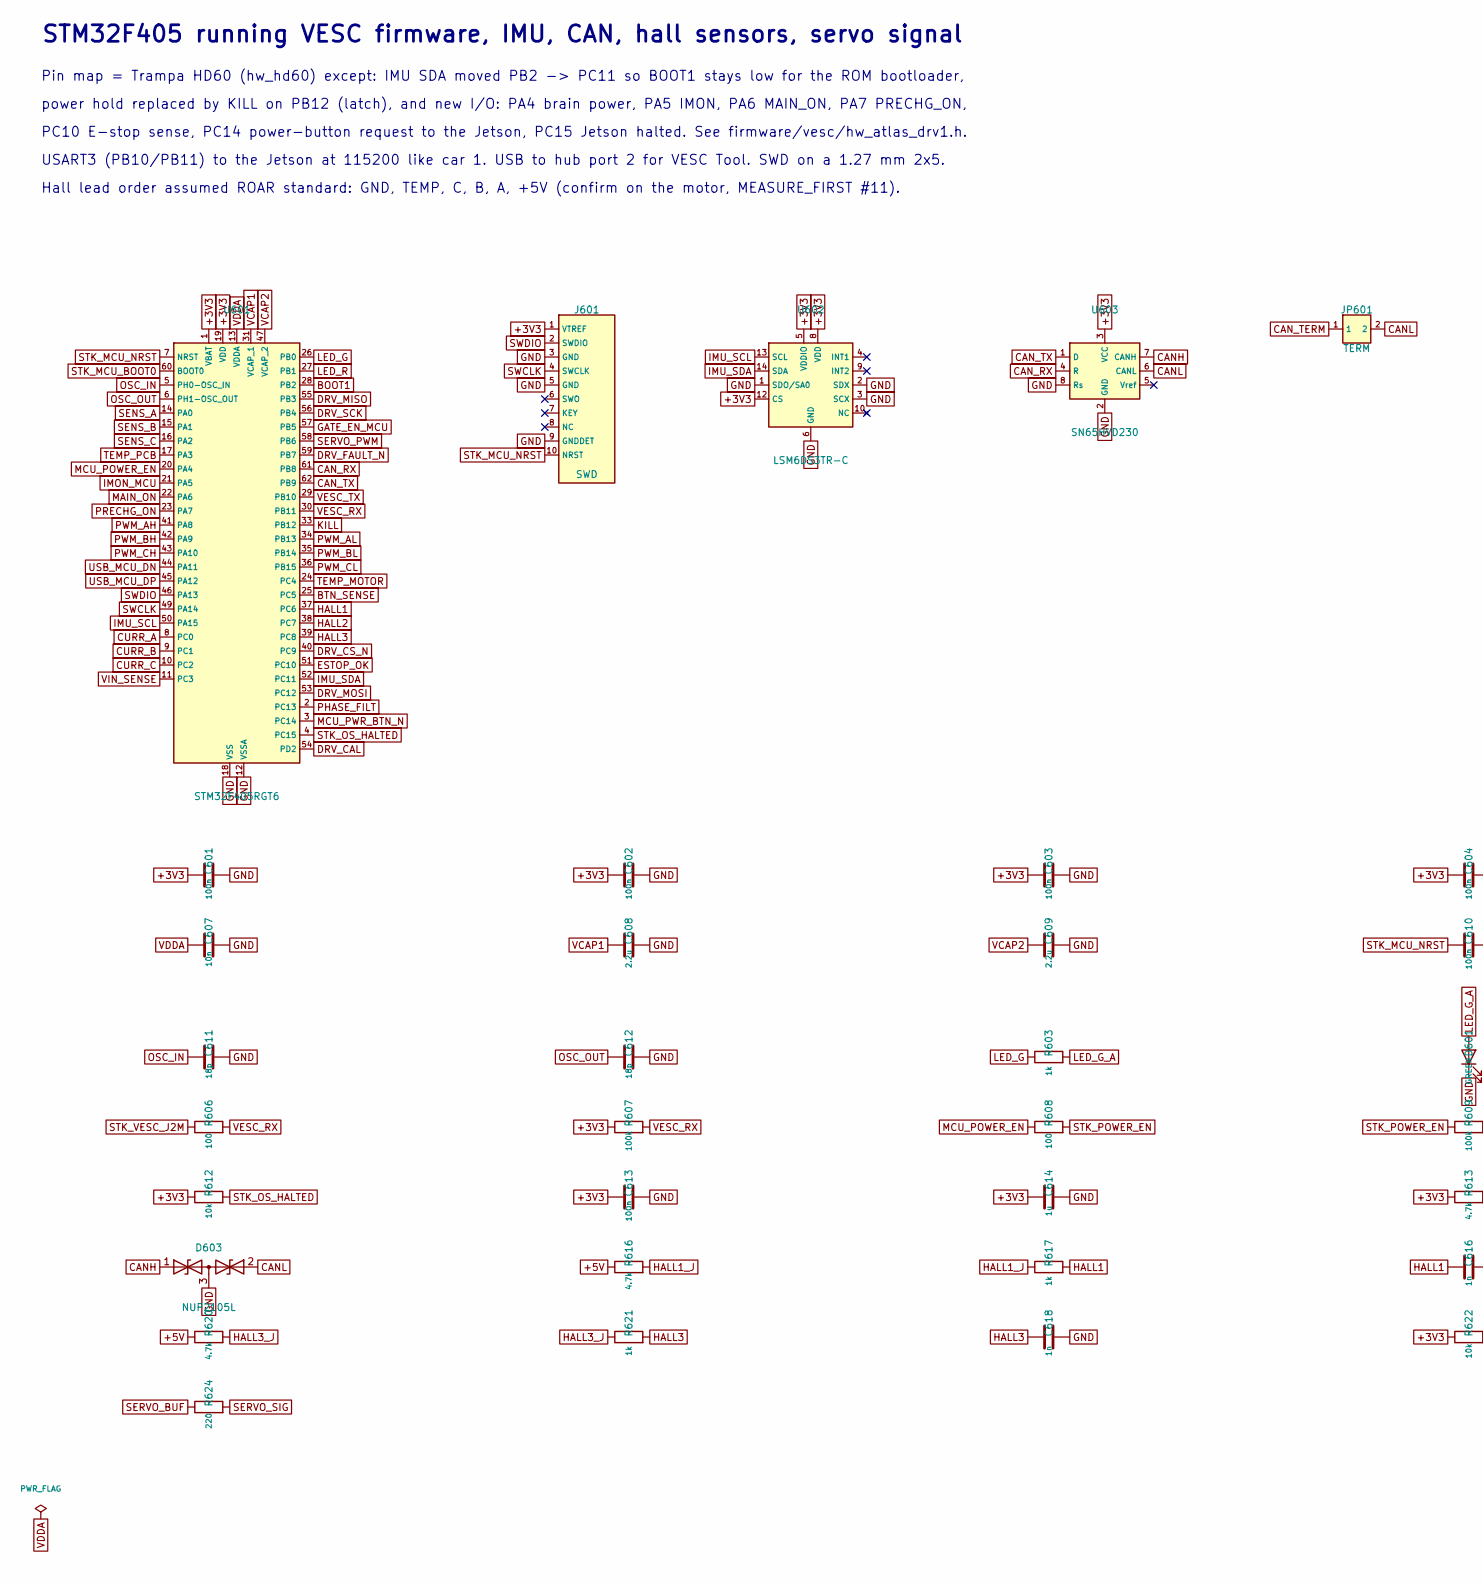
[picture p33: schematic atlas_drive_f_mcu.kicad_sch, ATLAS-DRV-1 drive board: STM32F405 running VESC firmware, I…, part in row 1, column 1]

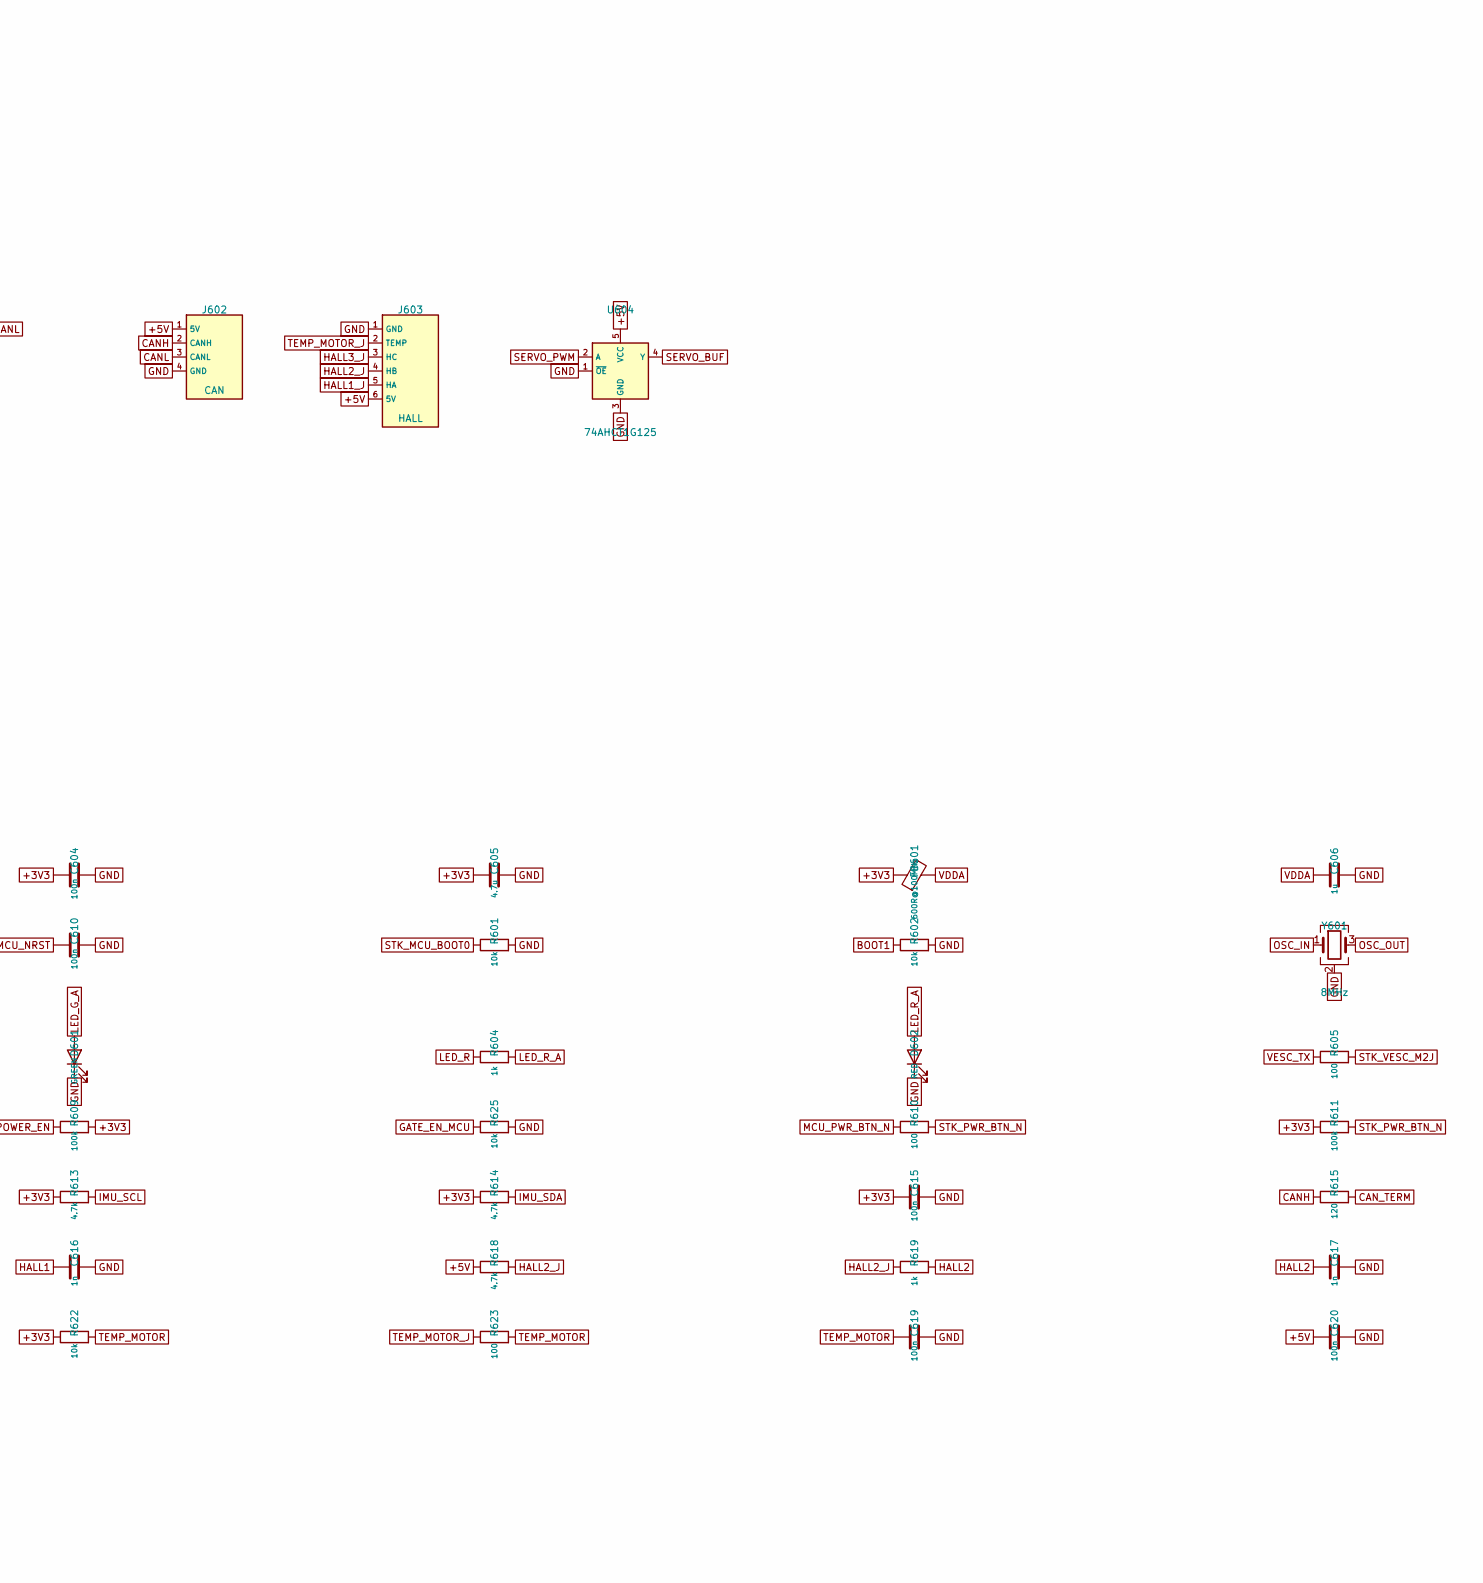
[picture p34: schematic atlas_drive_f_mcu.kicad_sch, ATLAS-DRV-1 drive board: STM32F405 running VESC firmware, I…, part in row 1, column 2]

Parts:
C601, C602, C603, C604, C610, C613, C615, C619, C620: 100n; C_0402_1005Metric
C605: 4.7u; C_0603_1608Metric
C606, C614: 1u; C_0603_1608Metric
C607: 10n; C_0402_1005Metric
C608, C609: 2.2u; C_0603_1608Metric
C611, C612: 18p; C_0402_1005Metric
C616, C617, C618: 1n; C_0402_1005Metric
D601: GREEN; LED_0603_1608Metric
D602: RED; LED_0603_1608Metric
D603: NUP2105L; SOT-23; MPN NUP2105LT1G
FB601: 600R@100MHz; L_0603_1608Metric; MPN BLM18KG601SN1D
J601: SWD; PinHeader_2x05_P1.27mm_Vertical_SMD; MPN FTSH-105-01-L-DV-K
J602: CAN; JST_GH_BM04B-GHS-TBT_1x04-1MP_P1.25mm_Vertical; MPN BM04B-GHS-TBT(LF)(SN)(N)
J603: HALL; JST_ZH_B6B-ZR_1x06_P1.50mm_Vertical; MPN B6B-ZR(LF)(SN)
JP601: TERM; SolderJumper-2_P1.3mm_Open_RoundedPad1.0x1.5mm
R601, R602, R612, R622, R625: 10k; R_0402_1005Metric
R603, R604, R617, R619, R621: 1k; R_0402_1005Metric
R605, R606, R608, R610, R623: 100; R_0402_1005Metric
R607, R609, R611: 100k; R_0402_1005Metric
R613, R614, R616, R618, R620: 4.7k; R_0402_1005Metric
R615: 120; R_0402_1005Metric
R624: 220; R_0402_1005Metric
U601: STM32F405RGT6; LQFP-64_10x10mm_P0.5mm; MPN STM32F405RGT6
U602: LSM6DS3TR-C; LGA-14_3x2.5mm_P0.5mm_LayoutBorder3x4y; MPN LSM6DS3TR-C
U603: SN65HVD230; SOIC-8_3.9x4.9mm_P1.27mm; MPN SN65HVD230DR
U604: 74AHCT1G125; SOT-353_SC-70-5; MPN SN74AHCT1G125DCKR
Y601: 8MHz; Crystal_SMD_3225-4Pin_3.2x2.5mm

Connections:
+3V3: C601.1, C602.1, C603.1, C604.1, C605.1, C613.1, C614.1, C615.1, FB601.1, J601.1 (VTREF), R607.1, R609.2, R611.1, R612.1, R613.1, R614.1, R622.1, U601.1 (VBAT), U601.19 (VDD), U601.32 (VDD), U601.48 (VDD), U601.64 (VDD), U602.5 (VDDIO), U602.8 (VDD), U602.12 (CS), U603.3 (VCC); also elsewhere on the board
+5V: C620.1, J602.1 (5V), J603.6 (5V), R616.1, R618.1, R620.1, U604.5 (VCC); also elsewhere on the board
BOOT1: R602.1, U601.28 (PB2)
BTN_SENSE: U601.25 (PC5); also elsewhere on the board
CANH: D603.1 (A1), J602.2 (CANH), R615.1, U603.7 (CANH)
CANL: D603.2 (A2), J602.3 (CANL), JP601.2, U603.6 (CANL)
CAN_RX: U601.61 (PB8), U603.4 (R)
CAN_TERM: JP601.1, R615.2
CAN_TX: U601.62 (PB9), U603.1 (D)
CURR_A: U601.8 (PC0); also elsewhere on the board
CURR_B: U601.9 (PC1); also elsewhere on the board
CURR_C: U601.10 (PC2); also elsewhere on the board
DRV_CAL: U601.54 (PD2); also elsewhere on the board
DRV_CS_N: U601.40 (PC9); also elsewhere on the board
DRV_FAULT_N: U601.59 (PB7); also elsewhere on the board
DRV_MISO: U601.55 (PB3); also elsewhere on the board
DRV_MOSI: U601.53 (PC12); also elsewhere on the board
DRV_SCK: U601.56 (PB4); also elsewhere on the board
ESTOP_OK: U601.51 (PC10); also elsewhere on the board
GATE_EN_MCU: R625.1, U601.57 (PB5); also elsewhere on the board
GND: C601.2, C602.2, C603.2, C604.2, C605.2, C606.2, C607.2, C608.2, C609.2, C610.2, C611.2, C612.2, C613.2, C614.2, C615.2, C616.2, C617.2, C618.2, C619.2, C620.2, D601.1 (K), D602.1 (K), D603.3 (common), J601.3 (GND), J601.5 (GND), J601.9 (GNDDET), J602.4 (GND), J603.1 (GND), R601.2, R602.2, R625.2, U601.12 (VSSA), U601.18 (VSS), U601.63 (VSS), U602.1 (SDO/SA0), U602.2 (SDX), U602.3 (SCX), U602.6 (GND), U602.7 (GND), U603.2 (GND), U603.8 (Rs), U604.1 (~OE), U604.3 (GND), Y601.2 (G), Y601.4 (G); also elsewhere on the board
HALL1: C616.1, R617.2, U601.37 (PC6)
HALL1_J: J603.5 (HA), R616.2, R617.1
HALL2: C617.1, R619.2, U601.38 (PC7)
HALL2_J: J603.4 (HB), R618.2, R619.1
HALL3: C618.1, R621.2, U601.39 (PC8)
HALL3_J: J603.3 (HC), R620.2, R621.1
IMON_MCU: U601.21 (PA5); also elsewhere on the board
IMU_SCL: R613.2, U601.50 (PA15), U602.13 (SCL)
IMU_SDA: R614.2, U601.52 (PC11), U602.14 (SDA)
KILL: U601.33 (PB12); also elsewhere on the board
LED_G: R603.1, U601.26 (PB0)
LED_G_A: D601.2 (A), R603.2
LED_R: R604.1, U601.27 (PB1)
LED_R_A: D602.2 (A), R604.2
MAIN_ON: U601.22 (PA6); also elsewhere on the board
MCU_POWER_EN: R608.1, U601.20 (PA4)
MCU_PWR_BTN_N: R610.1, U601.3 (PC14)
OSC_IN: C611.1, U601.5 (PH0-OSC_IN), Y601.1
OSC_OUT: C612.1, U601.6 (PH1-OSC_OUT), Y601.3
PHASE_FILT: U601.2 (PC13); also elsewhere on the board
PRECHG_ON: U601.23 (PA7); also elsewhere on the board
PWM_AH: U601.41 (PA8); also elsewhere on the board
PWM_AL: U601.34 (PB13); also elsewhere on the board
PWM_BH: U601.42 (PA9); also elsewhere on the board
PWM_BL: U601.35 (PB14); also elsewhere on the board
PWM_CH: U601.43 (PA10); also elsewhere on the board
PWM_CL: U601.36 (PB15); also elsewhere on the board
SENS_A: U601.14 (PA0); also elsewhere on the board
SENS_B: U601.15 (PA1); also elsewhere on the board
SENS_C: U601.16 (PA2); also elsewhere on the board
SERVO_BUF: R624.1, U604.4 (Y)
SERVO_PWM: U601.58 (PB6), U604.2 (A)
SERVO_SIG: R624.2; also elsewhere on the board
STK_MCU_BOOT0: R601.1, U601.60 (BOOT0); also elsewhere on the board
STK_MCU_NRST: C610.1, J601.10 (NRST), U601.7 (NRST); also elsewhere on the board
STK_OS_HALTED: R612.2, U601.4 (PC15); also elsewhere on the board
STK_POWER_EN: R608.2, R609.1; also elsewhere on the board
STK_PWR_BTN_N: R610.2, R611.2; also elsewhere on the board
STK_VESC_J2M: R606.1; also elsewhere on the board
STK_VESC_M2J: R605.2; also elsewhere on the board
SWCLK: J601.4 (SWCLK), U601.49 (PA14)
SWDIO: J601.2 (SWDIO), U601.46 (PA13)
TEMP_MOTOR: C619.1, R622.2, R623.2, U601.24 (PC4)
TEMP_MOTOR_J: J603.2 (TEMP), R623.1
TEMP_PCB: U601.17 (PA3); also elsewhere on the board
USB_MCU_DN: U601.44 (PA11); also elsewhere on the board
USB_MCU_DP: U601.45 (PA12); also elsewhere on the board
VCAP1: C608.1, U601.31 (VCAP_1)
VCAP2: C609.1, U601.47 (VCAP_2)
VDDA: C606.1, C607.1, FB601.2, U601.13 (VDDA)
VESC_RX: R606.2, R607.2, U601.30 (PB11)
VESC_TX: R605.1, U601.29 (PB10)
VIN_SENSE: U601.11 (PC3); also elsewhere on the board

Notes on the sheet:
STM32F405 running VESC firmware, IMU, CAN, hall sensors, servo signal
Pin map = Trampa HD60 (hw_hd60) except: IMU SDA moved PB2 -> PC11 so BOOT1 stays low for the ROM bootloader,
power hold replaced by KILL on PB12 (latch), and new I/O: PA4 brain power, PA5 IMON, PA6 MAIN_ON, PA7 PRECHG_ON,
PC10 E-stop sense, PC14 power-button request to the Jetson, PC15 Jetson halted. See firmware/vesc/hw_atlas_drv1.h.
USART3 (PB10/PB11) to the Jetson at 115200 like car 1. USB to hub port 2 for VESC Tool. SWD on a 1.27 mm 2x5.
Hall lead order assumed ROAR standard: GND, TEMP, C, B, A, +5V (confirm on the motor, MEASURE_FIRST #11).

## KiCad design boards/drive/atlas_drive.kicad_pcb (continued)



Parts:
C701: 4.7u 25V; C_0805_2012Metric
C702, C703: 390p; C_0402_1005Metric
C704, C705, C707: 10u 10V; C_0805_2012Metric
C706, C718: 4.7u 10V; C_0603_1608Metric
C708, C709: 22u 25V; C_1206_3216Metric
C710: 100n; C_0402_1005Metric
C711, C714, C721: 100n 50V; C_0402_1005Metric
C712, C713, C715, C716, C717, C722, C723, C724, C725, C726, C727, C728: 10u 25V; C_0805_2012Metric
C719, C720: 47n 16V; C_0402_1005Metric
D701: TPD4E05U06; USON-10_2.5x1.0mm_P0.5mm; MPN TPD4E05U06DQAR
D702: SMF24A; D_SOD-123F; MPN SMF24A
D703: AMBER; LED_0603_1608Metric
J701: USB_C_16P; USB_C_Receptacle_GCT_USB4105-xx-A_16P_TopMnt_Horizontal; MPN USB4105-GF-A
J702: EEPROM_PROG; PinHeader_1x04_P2.54mm_Vertical; not fitted
L701: 1u; L_Coilcraft_XAL5030-XXX; MPN XAL5030-102MEB
R701, R702, R703, R704, R708, R713: 10k; R_0402_1005Metric
R705: 100; R_0402_1005Metric
R706: 5.23k; R_0402_1005Metric
R707: 30.1k; R_0402_1005Metric
R709: 39k; R_0402_1005Metric
R710: 100k; R_0402_1005Metric
R711: 17.4k; R_0402_1005Metric
R712: 2.2k; R_0402_1005Metric
U701: TPS25751D; Texas_REF0038A_WQFN-38-2EP_6x4mm_P0.4_Gap0.19; MPN TPS25751DREFR
U702: M24512; SOIC-8_3.9x4.9mm_P1.27mm; MPN M24512-RMN6TP
U703: BQ25798; Texas_RQM0029A_VQFN-29_4x4mm_P0.4mm; MPN BQ25798RQMR

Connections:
+3V3: C704.1, R704.1, U701.38 (VIN_3V3); also elsewhere on the board
+5V: C707.1, U701.34 (PP5V); also elsewhere on the board
BATP: C727.1, C728.1, R705.1, U703.22 (BAT), U703.23 (BAT); also elsewhere on the board
CHG_BATP: R705.2, U703.18 (BATP)
CHG_BT1: C719.1, U703.4 (BTST1)
CHG_BT2: C720.1, U703.19 (BTST2)
CHG_ILIM: R709.2, R710.1, U703.17 (ILIM_HIZ)
CHG_INT_N: R703.2, U701.18 (~I2Cc_IRQ), U703.21 (~INT)
CHG_LED_A: D703.2 (A), R712.2
CHG_PMID: C714.1, C715.1, C716.1, C717.1, U703.29 (PMID)
CHG_PROG: R711.1, U703.20 (PROG)
CHG_QON_N: U703.12 (~QON); also elsewhere on the board
CHG_REGN: C718.1, R706.1, R709.1, R712.1, U703.5 (REGN)
CHG_SCL: J702.3 (SCL), R702.2, U701.17 (I2Cc_SCL), U702.6 (SCL), U703.14 (SCL)
CHG_SDA: J702.2 (SDA), R701.2, U701.16 (I2Cc_SDA), U702.5 (SDA), U703.15 (SDA)
CHG_STAT_N: D703.1 (K), R713.1, U703.1 (STAT)
CHG_SW1: C719.2, L701.1, U703.28 (SW1)
CHG_SW2: C720.2, L701.2, U703.26 (SW2)
CHG_TS: R706.2, R707.1, R708.1, U703.16 (TS)
GND: C701.2, C702.2, C703.2, C704.2, C705.2, C706.2, C707.2, C708.2, C709.2, C710.2, C711.2, C712.2, C713.2, C714.2, C715.2, C716.2, C717.2, C718.2, C721.2, C722.2, C723.2, C724.2, C725.2, C726.2, C727.2, C728.2, D701.3 (GND), D701.8 (GND), D702.2 (A), J701.A1 (GND), J701.A12 (GND), J701.B1 (GND), J701.B12 (GND), J701.SH (SHIELD), J702.4 (GND), R707.2, R708.2, R710.2, R711.2, U701.3 (ADCIN2), U701.5 (GPIO0), U701.6 (GPIO1), U701.7 (GPIO2), U701.11 (GND), U701.12 (GND), U701.14 (GND), U701.19 (GPIO3), U701.26 (GPIO4), U701.27 (GPIO5), U701.31 (GND), U701.36 (GPIO7), U701.37 (GPIO6), U701.39 (GND), U702.1 (E0), U702.2 (E1), U702.3 (E2), U702.4 (VSS), U702.7 (~WC), U703.10 (ACDRV2), U703.11 (ACDRV1), U703.13 (~CE), U703.27 (GND); also elsewhere on the board
PD_DRAIN: U701.15 (DRAIN), U701.30 (DRAIN), U701.40 (DRAIN)
PD_IRQ_N: R704.2, U701.10 (~I2Ct_IRQ)
PD_LDO1V5: C706.1, U701.4 (LDO_1V5)
PD_LDO3V3: C705.1, C710.1, J702.1 (3V3), R701.1, R702.1, R703.1, U701.1 (LDO_3V3), U701.2 (ADCIN1), U702.8 (VCC)
PPHV: C708.1, C709.1, C711.1, C712.1, C713.1, U701.20 (PPHV), U703.2 (VBUS), U703.3 (VBUS), U703.8 (VAC2), U703.9 (VAC1)
STK_CHG_STAT: R713.2; also elsewhere on the board
STK_I2C_SCL: U701.9 (I2Ct_SCL); also elsewhere on the board
STK_I2C_SDA: U701.8 (I2Ct_SDA); also elsewhere on the board
USBC_DN: D701.2 (IO2), D701.9 (IO2), J701.A7 (D-), J701.B7 (D-); also elsewhere on the board
USBC_DP: D701.1 (IO1), D701.10 (IO1), J701.A6 (D+), J701.B6 (D+); also elsewhere on the board
USB_CC1: C702.1, J701.A5 (CC1), U701.28 (CC1)
USB_CC2: C703.1, J701.B5 (CC2), U701.29 (CC2)
VBUS_C: C701.1, D702.1 (K), J701.A4 (VBUS), J701.A9 (VBUS), J701.B4 (VBUS), J701.B9 (VBUS), U701.23 (VBUS_IN), U701.32 (VBUS); also elsewhere on the board
VSYS: C721.1, C722.1, C723.1, C724.1, C725.1, C726.1, U703.25 (SYS); also elsewhere on the board

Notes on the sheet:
USB-C: TPS25751D PD sink + BQ25798 charger
TPS25751D in SafeMode (ADCIN1 = LDO_3V3, ADCIN2 = GND): loads its patch and configuration from the M24512 at 0x50
on I2Cc, negotiates up to 20 V and programs the BQ25798 (0x6B) on the same bus. Target port on the Jetson I2C.
BQ25798: PROG 17.4k = 4S, 1.5 MHz, 1 uH. TS fixed at 25 C (5.23k / 30.1k || 10k). ILIM_HIZ 39k / 100k = 3.25 A.
SYS output is VSYS (NVDC path): the brain board and the lidar run from it, from USB power when it is plugged in.
EEPROM image: TI Application Customization Tool (TPS25751). Header J702 can program it off-line.

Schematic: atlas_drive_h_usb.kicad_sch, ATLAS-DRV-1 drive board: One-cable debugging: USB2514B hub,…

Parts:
C801, C802, C803, C804, C805, C806, C808, C809, C813, C815: 100n; C_0402_1005Metric
C807, C814: 4.7u; C_0603_1608Metric
C810, C811: 18p; C_0402_1005Metric
C812: 1u; C_0603_1608Metric
D801: BLUE; LED_0603_1608Metric
D802: MMSZ4684; D_SOD-123; MPN MMSZ4684T1G
D803: GREEN; LED_0402_1005Metric
D804: YELLOW; LED_0402_1005Metric
R801, R809: 100k; R_0402_1005Metric
R802: 12.0k; R_0402_1005Metric
R803, R804, R808, R811: 10k; R_0402_1005Metric
R805: 470; R_0402_1005Metric
R806, R807: 47k; R_0402_1005Metric
R810, R813, R814: 1k; R_0402_1005Metric
R812: 100; R_0402_1005Metric
SW801: FLASH; SW_SPDT_PCM12; MPN PCM12SMTR
U801, U802: TS3USB30E; MSOP-10_3x3mm_P0.5mm; MPN TS3USB30EDGSR
U803: USB2514B; QFN-36-1EP_6x6mm_P0.5mm_EP3.7x3.7mm; MPN USB2514B-I/M2
U804: CP2102N-QFN24; QFN-24-1EP_4x4mm_P0.5mm_EP2.6x2.6mm; MPN CP2102N-A02-GQFN24
Y801: 24MHz; Crystal_SMD_3225-4Pin_3.2x2.5mm

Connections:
+3V3: C801.1, C802.1, C803.1, C804.1, C805.1, C806.1, C807.1, C813.1, C814.1, C815.1, R803.1, R806.1, R807.1, R810.1, R811.1, R813.1, R814.1, SW801.1 (A), U801.10 (VCC), U802.10 (VCC), U803.5 (VDDA33), U803.10 (VDDA33), U803.15 (VDD33), U803.23 (VDD33), U803.29 (VDDA33), U803.36 (VDDA33), U804.5 (VIO), U804.6 (VDD), U804.7 (VREGIN); also elsewhere on the board
CP_RST_N: R810.2, U804.9 (~RST)
CP_RXLED: D804.1 (K), U804.13 (GPIO.1/RXT)
CP_RXLED_A: D804.2 (A), R814.2
CP_TXD: R812.1, U804.21 (TXD)
CP_TXLED: D803.1 (K), U804.14 (GPIO.0/TXT)
CP_TXLED_A: D803.2 (A), R813.2
CP_VBUS: R811.2, U804.8 (VBUS)
FLASH_DN: U801.7 (D2-), U802.7 (D2-)
FLASH_DP: U801.3 (D2+), U802.3 (D2+)
FLASH_SEL: R801.1, SW801.2 (B), U801.1 (S), U802.1 (S)
GND: C801.2, C802.2, C803.2, C804.2, C805.2, C806.2, C807.2, C808.2, C809.2, C810.2, C811.2, C812.2, C813.2, C814.2, C815.2, D801.1 (K), D802.2 (A), R801.2, R802.2, R804.2, R809.2, SW801.3 (C), U801.5 (GND), U801.9 (~OE), U802.5 (GND), U802.9 (~OE), U803.11 (TEST), U803.37 (VSS), U804.2 (GND), U804.25 (GND), Y801.2 (G), Y801.4 (G); also elsewhere on the board
HUB_CFG0: R804.1, U803.24 (SCL/CFG_SEL0)
HUB_CFG1: R805.1, U803.25 (HS_IND/CFG_SEL1)
HUB_CRFILT: C808.1, U803.14 (CRFILT)
HUB_DN1_DN: U802.8 (D1-), U803.1 (DM_DN1)
HUB_DN1_DP: U802.2 (D1+), U803.2 (DP_DN1)
HUB_LED_A: D801.2 (A), R805.2
HUB_NONREM0: R807.2, U803.28 (SUSP_IND/NON_REM0)
HUB_NONREM1: R806.2, U803.22 (SDA/NON_REM1)
HUB_PLLFILT: C809.1, U803.34 (PLLFILT)
HUB_RBIAS: R802.1, U803.35 (RBIAS)
HUB_RST_N: C812.1, R803.2, U803.26 (RESET_N)
HUB_UP_DN: U801.8 (D1-), U803.30 (USBDM_UP)
HUB_UP_DP: U801.2 (D1+), U803.31 (USBDP_UP)
HUB_VBUS_DET: D802.1 (K), R808.2, R809.1, U803.27 (VBUS_DET)
HUB_XI: C810.1, U803.33 (XTALIN), Y801.1
HUB_XO: C811.1, U803.32 (XTALOUT), Y801.3
STK_CON_J2M: U804.20 (RXD); also elsewhere on the board
STK_CON_M2J: R812.2; also elsewhere on the board
STK_USB0_DN: U802.6 (D-); also elsewhere on the board
STK_USB0_DP: U802.4 (D+); also elsewhere on the board
USBC_DN: U801.6 (D-); also elsewhere on the board
USBC_DP: U801.4 (D+); also elsewhere on the board
USB_CP_DN: U803.6 (DM_DN3), U804.4 (D-)
USB_CP_DP: U803.7 (DP_DN3), U804.3 (D+)
USB_MCU_DN: U803.3 (DM_DN2); also elsewhere on the board
USB_MCU_DP: U803.4 (DP_DN2); also elsewhere on the board
VBUS_C: R808.1; also elsewhere on the board

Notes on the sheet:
One-cable debugging: USB2514B hub, CP2102N console, flash-mode switch
Normal: USB-C -> hub. Port 1 Jetson USB0 (L4T USB networking), port 2 STM32 (VESC Tool), port 3 CP2102N (console).
FLASH switch: two TS3USB30E connect USB-C straight to Jetson USB0 (NVIDIA asks for a direct link in recovery).
Hub straps: CFG_SEL = 00 (self-powered, straps on), NON_REM = 11 (ports 1-3 fixed). RBIAS 12.0k 1%.
VBUS_DET: VBUS can be 20 V after PD, so a 10k + 3.3 V low-current zener clamps it.

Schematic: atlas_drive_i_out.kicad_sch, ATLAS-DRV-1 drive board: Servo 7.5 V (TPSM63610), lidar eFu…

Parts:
C901, C902, C903: 10u 50V; C_1210_3225Metric; MPN GRM32ER71H106KA12L
C904: 100n 50V; C_0402_1005Metric
C905: 1u 25V; C_0603_1608Metric
C906, C907, C908, C909: 47u 16V; C_1210_3225Metric; MPN GRM32EC81C476ME15L
C910: 220u 16V; CP_Elec_8x10; MPN 16SVPF220M
C911, C913: 1u 50V; C_0805_2012Metric
C912: 22n; C_0402_1005Metric
D901: SMBJ20A; D_SMB; MPN SMBJ20A
J901: SERVO; PinHeader_1x03_P2.54mm_Vertical
J902: LIDAR_PWR; TerminalBlock_Phoenix_PT-1,5-2-3.5-H_1x02_P3.50mm_Horizontal; MPN 1984617
J903: FAN; FanPinHeader_1x04_P2.54mm_Vertical
R901, R904, R907, R909, R911, R912: 100k; R_0402_1005Metric
R902: 16.2k; R_0402_1005Metric
R903: 15.8k; R_0402_1005Metric
R905: 15.4k; R_0402_1005Metric
R906: 100; R_0402_1005Metric
R908: 732k; R_0402_1005Metric
R910: 12k; R_0402_1005Metric
U901: TPSM63610; TI_RDF0022A_B3QFN-22_6.5x7.5mm; MPN TPSM63610RDFR
U902: TPS26600; HTSSOP-16-1EP_4.4x5mm_P0.65mm_EP3.4x5mm; MPN TPS26600PWPR

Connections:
+3V3: R907.1, R912.1; also elsewhere on the board
+5V: J903.2 (+5V); also elsewhere on the board
GND: C901.2, C902.2, C903.2, C904.2, C905.2, C906.2, C907.2, C908.2, C909.2, C910.2, C911.2, C912.2, C913.2, D901.2 (A), J901.3 (GND), J902.2 (-), J903.1 (GND), R902.2, R903.2, R905.2, R909.2, R910.2, R911.2, U901.7 (AGND), U901.11 (AGND), U901.15 (SYNC/MODE), U901.19 (PGND), U901.20 (PGND), U901.21 (AGND), U901.22 (AGND), U902.5 (OVP), U902.8 (RTN), U902.9 (GND), U902.17 (RTN); also elsewhere on the board
LIDAR_V: C913.1, D901.1 (K), J902.1 (+), U902.15 (OUT), U902.16 (OUT); also elsewhere on the board
LID_DVDT: C912.1, U902.12 (dVdT)
LID_FLT_N: R912.2, U902.14 (~FLT); also elsewhere on the board
LID_ILIM: R910.1, U902.11 (ILIM)
LID_UVLO: R908.2, R909.1, U902.3 (UVLO)
SERVO_SIG: J901.1 (SIG); also elsewhere on the board
SERVO_V: C905.1, C906.1, C907.1, C908.1, C909.1, C910.1, J901.2 (V+), R904.1, U901.5 (VLDOIN), U901.9 (VOUT), U901.10 (VOUT); also elsewhere on the board
SRV_CBOOT: R906.2, U901.3 (CBOOT)
SRV_EN: R901.2, R902.1, U901.17 (EN)
SRV_FB: R904.2, R905.1, U901.8 (FB)
SRV_PG: R907.2, U901.13 (PG); also elsewhere on the board
SRV_RBOOT: R906.1, U901.2 (RBOOT)
SRV_RT: R903.1, U901.12 (RT)
SRV_VCC: U901.6 (VCC), U901.14 (SPSP)
STK_LIDAR_EN: R911.1, U902.7 (~SHDN); also elsewhere on the board
VM: C901.1, C902.1, C903.1, C904.1, R901.1, U901.1 (VIN), U901.18 (VIN); also elsewhere on the board
VSYS: C911.1, R908.1, U902.1 (IN), U902.2 (IN); also elsewhere on the board

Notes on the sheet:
Servo 7.5 V (TPSM63610), lidar eFuse (TPS26600), fan
TPSM63610 from VM: RFBT 100k / RFBB 15.4k = 7.49 V, RT 15.8k = 1 MHz, EN divider 100k / 16.2k = on above 9 V.
Output 4 x 47 uF 16 V + 220 uF polymer for servo stall pulses (8 A, 10 A peak).
TPS26600 from VSYS: ILIM 12k = 1 A, dVdT 22 nF, UVLO 10 V. SHDN from the Jetson (LIDAR_EN), off by default.

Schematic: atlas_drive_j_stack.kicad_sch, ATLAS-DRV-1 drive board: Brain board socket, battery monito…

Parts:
C1001, C1002, C1004: 100n; C_0402_1005Metric
C1003: 10n 50V; C_0402_1005Metric
H1001, H1002, H1003, H1004, H1005, H1006, H1007, H1008: M3; MountingHole_3.2mm_M3_Pad_Via
J1001: STACK_2x20; PinSocket_2x20_P2.54mm_Vertical; MPN SSQ-120-03-G-D
R1001, R1002: 10k; R_0402_1005Metric
R1003, R1004: 10; R_0402_1005Metric
R1005: 1k; R_0402_1005Metric
TP1001: STK_SPARE1; TestPoint_Pad_D1.0mm
TP1002: STK_SPARE2; TestPoint_Pad_D1.0mm
TP1003: STK_CAN_TX; TestPoint_Pad_D1.0mm
TP1004: STK_CAN_RX; TestPoint_Pad_D1.0mm
TP1005, TP1006: GND; TestPoint_Pad_D1.0mm
TP1007: BATP; TestPoint_Pad_D1.0mm
TP1008: VM; TestPoint_Pad_D1.0mm
TP1009: VSYS; TestPoint_Pad_D1.0mm
TP1010: +5V; TestPoint_Pad_D1.0mm
TP1011: +3V3; TestPoint_Pad_D1.0mm
TP1012: 3V3_AON; TestPoint_Pad_D1.0mm
TP1013: SERVO_V; TestPoint_Pad_D1.0mm
TP1014: LIDAR_V; TestPoint_Pad_D1.0mm
TP1015: SRV_PG; TestPoint_Pad_D1.0mm
TP1016: LID_FLT_N; TestPoint_Pad_D1.0mm
TP1017: CURR_A; TestPoint_Pad_D1.0mm
TP1018: SENS_A; TestPoint_Pad_D1.0mm
U1001: INA228; MSOP-10_3x3mm_P0.5mm; MPN INA228AIDGSR
U1002: 24AA02; SOT-23-5; MPN 24AA02T-I/OT

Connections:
3V3_AON: TP1012.1; also elsewhere on the board
+3V3: C1001.1, C1004.1, J1001.35, R1001.1, R1002.1, TP1011.1, U1001.6 (VS), U1002.5 (VCC); also elsewhere on the board
+5V: TP1010.1; also elsewhere on the board
BATP: R1005.1, TP1007.1; also elsewhere on the board
BMS_KS1: R1004.1; also elsewhere on the board
BMS_KS2: R1003.1; also elsewhere on the board
CURR_A: TP1017.1; also elsewhere on the board
ESTOP_OK: J1001.26; also elsewhere on the board
GND: C1001.2, C1003.2, C1004.2, H1001.1, H1002.1, H1003.1, H1004.1, H1005.1, H1006.1, H1007.1, H1008.1, J1001.7, J1001.8, J1001.9, J1001.10, J1001.13, J1001.14, J1001.29, J1001.30, J1001.36, J1001.37, J1001.38, J1001.39, J1001.40, TP1005.1, TP1006.1, U1001.1 (A1), U1001.2 (A0), U1001.7 (GND), U1002.2 (VSS), U1002.4 (WP); also elsewhere on the board
INA_INN: C1002.2, R1004.2, U1001.9 (IN-)
INA_INP: C1002.1, R1003.2, U1001.10 (IN+)
INA_VBUS: C1003.1, R1005.2, U1001.8 (VBUS)
LIDAR_V: TP1014.1; also elsewhere on the board
LID_FLT_N: TP1016.1; also elsewhere on the board
SENS_A: TP1018.1; also elsewhere on the board
SERVO_V: TP1013.1; also elsewhere on the board
SRV_PG: TP1015.1; also elsewhere on the board
STK_CAN_RX: J1001.34, TP1004.1
STK_CAN_TX: J1001.33, TP1003.1
STK_CHG_STAT: J1001.27; also elsewhere on the board
STK_CON_J2M: J1001.17; also elsewhere on the board
STK_CON_M2J: J1001.18; also elsewhere on the board
STK_I2C_SCL: J1001.19, R1001.2, U1001.5 (SCL), U1002.1 (SCL); also elsewhere on the board
STK_I2C_SDA: J1001.20, R1002.2, U1001.4 (SDA), U1002.3 (SDA); also elsewhere on the board
STK_LIDAR_EN: J1001.28; also elsewhere on the board
STK_MCU_BOOT0: J1001.25; also elsewhere on the board
STK_MCU_NRST: J1001.24; also elsewhere on the board
STK_OS_HALTED: J1001.22; also elsewhere on the board
STK_POWER_EN: J1001.23; also elsewhere on the board
STK_PWR_BTN_N: J1001.21; also elsewhere on the board
STK_SPARE1: J1001.31, TP1001.1
STK_SPARE2: J1001.32, TP1002.1
STK_USB0_DN: J1001.12; also elsewhere on the board
STK_USB0_DP: J1001.11; also elsewhere on the board
STK_VESC_J2M: J1001.15; also elsewhere on the board
STK_VESC_M2J: J1001.16; also elsewhere on the board
VM: TP1008.1; also elsewhere on the board
VSYS: J1001.1, J1001.2, J1001.3, J1001.4, J1001.5, J1001.6, TP1009.1; also elsewhere on the board

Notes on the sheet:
Brain board socket, battery monitor, board ID
Pin map from boards/stack/stack.py (shared with the brain board). Odd pins on the car-left row, pin 1 at the rear.
INA228 at 0x40 on the Jetson I2C: pack current on the BMS shunt (0.5 mOhm), pack voltage on B+.
The Jetson I2C is pulled up on the module; the 10k here keep it defined while the brain board is off.



Board: 6 copper layers, 140.0 x 90.0 mm, 409 parts (110 on the bottom side), 264 nets.

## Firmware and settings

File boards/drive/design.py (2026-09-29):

"""ATLAS-DRV-1, the drive board: battery protection, main switch, USB-C charging, ESC, servo
and lidar supplies, USB debug hub, and the socket for the brain board.

Single source of truth for the schematic and the PCB. Run tools/build.py drive.
Values carry a short reason where the datasheet asks for a design choice.
"""
import os
import sys

HERE = os.path.dirname(os.path.abspath(__file__))
sys.path.insert(0, os.path.join(HERE, '..', 'tools'))
sys.path.insert(0, os.path.join(HERE, '..', 'stack'))
from eda import Design, P_IN, PAS  # noqa: E402
from chips import *  # noqa: E402,F401,F403
import stack  # noqa: E402

d = Design('atlas_drive', 'ATLAS-DRV-1 drive board', rev='0.1')
TI = 'Texas Instruments'
MUR_10U50 = 'GRM32ER71H106KA12L'      # 10 uF 50 V X7R 1210 (TPSM63610 datasheet table 7-2)

# =============================================================================== A. pack
d.block('A_PACK', 'Pack connection', [
    'Pack power leads: 10 AWG soldered into B+ and B- (SolderWire 6 mm2 pads).',
    'Sense lead: 7-pin JST-XH side entry. B0 is the bottom of cell 1, B4 the top of cell 4.',
    'B- is the cell stack bottom (BATN). Board ground (GND) is PACK-, after the BMS FETs.',
])
PAD6 = 'Connector_Wire:SolderWire-6sqmm_1x01_D3.5mm_OD7mm'
d.chip('J', conn('PAD_BAT+', 1, PAD6, desc='pack + lead, 10 AWG'), {'1': 'BATP'}, value='B+', in_bom='no')
d.chip('J', conn('PAD_BAT-', 1, PAD6, desc='pack - lead, 10 AWG'), {'1': 'BATN'}, value='B-', in_bom='no')
d.chip('J', conn('PACK_SENSE', 7, 'Connector_JST:JST_XH_S7B-XH-A_1x07_P2.50mm_Horizontal', mpn='S7B-XH-A(LF)(SN)',
                  mfr='JST', desc='pack sense lead: B0..B4, NTC, NTC return',
                  names=['B0', 'B1', 'B2', 'B3', 'B4', 'NTC', 'NTC_RTN']),
       {'B0': 'CELL0', 'B1': 'CELL1', 'B2': 'CELL2', 'B3': 'CELL3', 'B4': 'CELL4', 'NTC': 'BMS_TS', 'NTC_RTN': 'BATN'})
d.D('D', 'SMBJ20A', 'BATN', 'BATP', 'Diode_SMD:D_SMB', kind='Z', mpn='SMBJ20A', mfr='Littelfuse',
    desc='TVS across the pack terminals, 20 V standoff, 32.4 V clamp')

# =============================================================================== B. BMS
d.block('B_BMS', 'Battery protection: BQ7791508, 4S, low-side FETs', [
    'BQ7791508: OV 4.20 V, UV 3.00 V, OCD1 70 mV / 1.4 s, OCD2 140 mV / 0.7 s, SCD 300 mV / 0.4 ms, OCC 60 mV.',
    'Sense 0.5 mOhm: OCD1 140 A, OCD2 280 A, SCD 600 A, OCC 120 A. VESC input limit (90 A) stays under OCD1.',
    '4S: CCFG to AVDD; VC5 shorted to VC4 at the pins (datasheet 11). Internal balancing: 33 Ohm / 1 uF per input (RINI, CINI).',
    'DSG FETs source on the shunt side, CHG FETs source on PACK- (GND), drains common (FET_MID).',
    'CTRC/CTRD tied to VSS = drivers always enabled. PRES held high through a divider (recommended max 16 V).',
])
U = d.chip('U', BQ77915, {'VDD': 'BMS_VDD', 'AVDD': 'BMS_AVDD', 'VC5': 'BMS_VC4', 'VC4': 'BMS_VC4', 'VC3': 'BMS_VC3',
                           'VC2': 'BMS_VC2', 'VC1': 'BMS_VC1', 'VC0': 'BMS_VC0', 'SRP': 'BMS_SRP', 'SRN': 'BMS_SRN',
                           'TS': 'BMS_TS', 'VTB': 'BMS_VTB', 'DSG': 'BMS_DSG', 'CHG': 'BMS_CHG', 'LD': 'BMS_LD',
                           'LPWR': None, 'CBI': 'BATN', 'OCDP': 'BMS_OCDP', 'CCFG': 'BMS_AVDD', 'CBO': None,
                           'PRES': 'BMS_PRES', 'CTRC': 'BATN', 'CTRD': 'BATN', 'VSS': 'BATN'})
for i in range(5):
    d.R('R', '33', f'CELL{i}', f'BMS_VC{i}', size='0805', desc='cell input filter, 33 Ohm 0805 (balancing current ~50 mA)')
for i in range(1, 5):
    d.C('C', '1u 16V', f'BMS_VC{i}', f'BMS_VC{i - 1}', size='0603', desc='cell input filter 1 uF X7R')
d.R('R', '1k', 'CELL4', 'BMS_VDD', desc='VDD filter (RVDD)')
d.C('C', '1u 25V', 'BMS_VDD', 'BATN', size='0603', desc='VDD filter (CVDD)')
d.C('C', '1u 6.3V', 'BMS_AVDD', 'BATN', desc='AVDD')
d.R('R', '10k', 'BMS_VTB', 'BMS_TS', desc='thermistor pull-up to VTB, 1%')
d.R('R', '750k', 'BMS_OCDP', 'BATN', desc='OCDP: OCD1 1.42 s / OCD2 0.70 s (table 9-3)')
d.R('R', '470k', 'BMS_LD', 'GND', desc='load removal detect')
d.R('R', '470k', 'CELL4', 'BMS_PRES', desc='PRES divider top: 11.4 V at 16.8 V')
d.R('R', '1M', 'BMS_PRES', 'BATN', desc='PRES divider bottom')
d.R('R', '100', 'BMS_KS1', 'BMS_SRP', desc='sense filter RS')
d.R('R', '100', 'BMS_KS2', 'BMS_SRN', desc='sense filter RS')
d.C('C', '100n', 'BMS_SRP', 'BMS_SRN', desc='sense filter CS')
d.chip('R', SHUNT4, {'I1': 'BATN', 'I2': 'BMS_RSN', 'S1': 'BMS_KS1', 'S2': 'BMS_KS2'}, value='0.5m',
       mpn='BVR-Z-R0005-1.0', mfr='Isabellenhuette', desc='BMS sense 0.5 mOhm 4-terminal 4026')
d.R('R', '4.53k', 'BMS_DSG', 'DSG_G', desc='DSG gate resistor (RDSG)')
d.R('R', '1M', 'DSG_G', 'BMS_RSN', desc='DSG gate-source (RGS_DSG)')
d.R('R', '1k', 'BMS_CHG', 'CHG_G', desc='CHG gate resistor (RCHG)')
d.R('R', '1M', 'CHG_G', 'GND', desc='CHG gate-source (RGS_CHG)')
for i in range(4):
    d.chip('Q', NFET_Q5B, {'G': 'DSG_G', 'D': 'FET_MID', 'S': 'BMS_RSN'}, desc='BMS discharge FET')
    d.chip('Q', NFET_Q5B, {'G': 'CHG_G', 'D': 'FET_MID', 'S': 'GND'}, desc='BMS charge FET')

# =============================================================================== C. main switch
d.block('C_SWITCH', 'Main switch: TPS48111 + 4 FETs, MCU-sequenced precharge', [
    'EN from the power latch. The MCU turns on INP_G (precharge through 10 Ohm), checks VM, then INP (main FETs).',
    'RSNS 0.2 mOhm. SCP: RISCP 4.02k -> 350 A in 1.2 us. OCP: RIWRN 39.2k, RSET 100 -> 150 A for 10 ms (CTMR 680 nF).',
    'IMON: gain 0.9 x 5.1k / 100 = 46 -> 150 A reads 1.38 V on PA5. Auto-retry after 15 s.',
    'CBST 2.2 uF (4 x 118 nC gate charge). Remote temperature: MMBT3904 at the FETs on DIODE.',
])
d.chip('U', TPS48111, {'VS': 'BATP', 'CS+': 'SW_CSP', 'CS-': 'SW_KS2', 'ISCP': 'SW_ISCP', 'EN/UVLO': 'SW_EN',
                        'INP_G': 'SW_INPG', 'INP': 'SW_INP', 'FLT_T': 'SW_FLT_N', 'FLT_I': 'SW_FLT_N', 'IMON': 'SW_IMON',
                        'IWRN': 'SW_IWRN', 'TMR': 'SW_TMR', 'DIODE': 'SW_DIODE', 'BST': 'SW_BST', 'PU': 'SW_GATE',
                        'PD': 'SW_GATE', 'SRC': 'VM', 'G': 'PRE_G0', 'GND': 'GND'})
d.chip('R', SHUNT4, {'I1': 'BATP', 'I2': 'SW_IN', 'S1': 'SW_KS1', 'S2': 'SW_KS2'}, value='0.2m',
       mpn='BVR-Z-R0002-1.0', mfr='Isabellenhuette', desc='main switch sense 0.2 mOhm 4-terminal 4026')
d.R('R', '100', 'SW_KS1', 'SW_CSP', desc='RSET 100 Ohm 1%')
d.R('R', '4.02k', 'SW_KS1', 'SW_ISCP', desc='RISCP: short circuit 350 A (eq. 11)')
d.R('R', '39.2k', 'SW_IWRN', 'GND', desc='RIWRN: overcurrent 150 A (eq. 6)')
d.C('C', '680n', 'SW_TMR', 'GND', desc='CTMR: 10 ms overcurrent delay, 15 s retry')
d.R('R', '5.1k', 'SW_IMON', 'GND', desc='RIMON: 46 V/V')
d.C('C', '2.2u 25V', 'SW_BST', 'VM', size='0805', desc='bootstrap cap BST-SRC')
d.R('R', '10k', 'LATCH_Q', 'SW_EN', desc='EN from the latch')
d.R('R', '100k', 'SW_EN', 'GND', desc='EN pull-down')
d.R('R', '100k', 'SW_INP', 'GND', desc='INP off by default')
d.R('R', '100k', 'SW_INPG', 'GND', desc='INP_G off by default')
d.R('R', '1k', 'MAIN_ON', 'SW_INP', desc='from PA6')
d.R('R', '1k', 'PRECHG_ON', 'SW_INPG', desc='from PA7')
d.C('C', '100n 50V', 'BATP', 'GND', desc='VS decoupling')
d.chip('Q', NPN_SOT23, {'B': 'SW_DIODE', 'C': 'SW_DIODE', 'E': 'GND'}, desc='remote temperature diode at the main FETs')
d.R('R', '1k', 'SW_IMON', 'IMON_MCU', desc='IMON to PA5; limits clamp current')
d.C('C', '100n', 'IMON_MCU', 'GND', desc='IMON filter')
d.R('R', '1k', '+3V3', 'SW_FLT_LED', desc='fault LED')
d.LED('D', 'RED', 'SW_FLT_LED', 'SW_FLT_N')
for i in range(4):
    d.R('R', '2.2', 'SW_GATE', f'SW_G{i}', desc='gate resistor per FET (current sharing)')
    d.chip('Q', NFET_Q5B, {'G': f'SW_G{i}', 'D': 'SW_IN', 'S': 'VM'}, desc='main switch FET')
d.R('R', '470', 'PRE_G0', 'PRE_G', desc='precharge gate Rg (datasheet 220-470 Ohm)')
d.chip('Q', NFET_Q5B, {'G': 'PRE_G', 'D': 'PRE_D', 'S': 'VM'}, desc='precharge FET')
for _ in range(2):
    d.R('R', '22', 'SW_IN', 'PRE_D', size='2512', mpn='CRCW251222R0FKEGHP', mfr='Vishay',
        desc='precharge resistor, 2 x 22 Ohm pulse-proof 2512 in parallel (11 Ohm, tau 16 ms): each takes 0.15 J per '
             'switch-on, under its single-pulse rating (sim/precharge.py; one 10 Ohm 2512 was over it)')
d.D('D', 'SMCJ20A', 'GND', 'VM', 'Diode_SMD:D_SMC', kind='Z', mpn='SMCJ20A', mfr='Littelfuse',
    desc='motor bus TVS 1500 W: regen with the BMS open')

# =============================================================================== D. power latch and logic supplies
d.block('D_POWER', 'Power button latch and logic supplies', [
    'TPS70933 makes 3V3_AON from B+ (1 uA). SN74LVC1G74 is the on/off latch: button -> PRE, MCU KILL -> CLR.',
    'A reset or crash of the MCU does not turn the car off; only KILL (PB12 high) or pulling the pack does.',
    'LATCH_Q enables the TPS48111 and the DRV8323R buck (nSHDN). Buck: VIN from B+, 5.0 V (54.9k / 10k, 0.765 V FB).',
    'TLV75533P makes +3V3 from +5V. The button also pulls the charger QON low (exits ship mode).',
])
d.chip('U', TPS709, {'IN': 'BATP', 'EN': 'BATP', 'OUT': '3V3_AON', 'NC': None, 'GND': 'GND'})
d.C('C', '1u 50V', 'BATP', 'GND', size='0603', desc='LDO input')
d.C('C', '2.2u', '3V3_AON', 'GND', size='0603', desc='LDO output')
d.chip('U', LVC1G74, {'VCC': '3V3_AON', 'CLK': 'GND', 'D': 'GND', '~{PRE}': 'BTN_N', '~{CLR}': 'LATCH_CLR_N',
                       'Q': 'LATCH_Q', '~{Q}': None, 'GND': 'GND'})
d.C('C', '100n', '3V3_AON', 'GND', desc='latch decoupling')
d.R('R', '100k', '3V3_AON', 'BTN_N', desc='button pull-up')
d.C('C', '10n', 'BTN_N', 'GND', desc='button debounce')
d.R('R', '100k', '3V3_AON', 'LATCH_CLR_N', desc='CLR pull-up')
d.C('C', '1u', 'LATCH_CLR_N', 'GND', size='0603', desc='power-on clear: latch starts off when the pack is connected')
d.chip('Q', NMOS_SOT23, {'G': 'KILL_G', 'D': 'LATCH_CLR_N', 'S': 'GND'}, desc='MCU kill: clears the latch')
d.R('R', '1k', 'KILL', 'KILL_G', desc='from PB12')
d.R('R', '100k', 'KILL_G', 'GND', desc='kill off while the MCU is in reset')
d.stock('SW', 'Switch:SW_Push', 'POWER', 'Button_Switch_SMD:SW_Push_1P1T_NO_CK_KMR2', {'1': 'BTN_N', '2': 'GND'},
        mpn='KMR211NG LFS', mfr='C&K', desc='on-board power button')
d.chip('J', conn('BTN_EXT', 2, 'Connector_JST:JST_PH_S2B-PH-K_1x02_P2.00mm_Horizontal', mpn='S2B-PH-K-S(LF)(SN)', mfr='JST',
                  desc='remote power button (parallel to SW1)'), {'1': 'BTN_N', '2': 'GND'})
d.chip('U', LVC1G34, {'VCC': '+3V3', 'A': 'BTN_N', 'Y': 'BTN_SENSE', 'GND': 'GND', 'NC': None})
d.C('C', '100n', '+3V3', 'GND', desc='button buffer decoupling')
d.D('D', 'BAT54WS', 'CHG_QON_N', 'BTN_N', 'Diode_SMD:D_SOD-323', kind='S', mpn='BAT54WS', mfr='Nexperia',
    desc='button also pulls charger QON low (ship-mode exit)')
d.R('R', '10k', 'LATCH_Q', 'BUCK_EN', desc='buck enable from the latch')
# DRV8323R buck part (pins on U30 in the ESC sheet): VIN, nSHDN, SW, CB, FB
d.R('R', '10', 'BATP', 'BUCK_VIN', size='0603', desc='buck input filter')
d.C('C', '4.7u 50V', 'BUCK_VIN', 'GND', size='1206', desc='buck input (CVIN)')
d.C('C', '100n 50V', 'BUCK_VIN', 'GND', desc='buck input HF')
d.C('C', '100n 16V', 'BUCK_CB', 'BUCK_SW', desc='buck bootstrap (CBOOT)')
d.D('D', 'PMEG6010CEH', 'GND', 'BUCK_SW', 'Diode_SMD:D_SOD-123F', kind='S', mpn='PMEG6010CEH', mfr='Nexperia',
    desc='buck catch diode 60 V 1 A (DSW)')
d.L('L', '22u', 'BUCK_SW', '+5V', 'Inductor_SMD:L_Bourns-SRN4018', mpn='SRN4018-220M', mfr='Bourns',
    desc='buck inductor 22 uH (0.7 MHz, 16.8 V -> 5 V, 0.35 A)')
d.C('C', '22u 10V', '+5V', 'GND', size='0805', desc='buck output')
d.C('C', '22u 10V', '+5V', 'GND', size='0805', desc='buck output')
d.R('R', '54.9k', '+5V', 'BUCK_FB', desc='FB top: 0.765 x (1 + 54.9/10) = 4.96 V')
d.R('R', '10k', 'BUCK_FB', 'GND', desc='FB bottom')
d.chip('U', TLV755, {'IN': '+5V', 'EN': '+5V', 'OUT': '+3V3', 'NC': None, 'GND': 'GND'})
d.C('C', '1u', '+5V', 'GND', size='0603', desc='LDO in')
d.C('C', '10u 10V', '+3V3', 'GND', size='0805', desc='LDO out / 3.3 V bulk')
d.R('R', '1k', '+3V3', 'PWR_LED', desc='power LED')
d.LED('D', 'GREEN', 'PWR_LED', 'GND')

# =============================================================================== E. ESC
d.block('E_ESC', 'ESC power stage: DRV8323RS + 12 x CSD18510Q5B + 3 shunts', [
    'VESC-6 class, Trampa HD60 pin map (firmware/vesc/hw_atlas_drv1). 6x PWM from TIM1: PA8-10 high, PB13-15 low.',
    'Two FETs per switch, 2.2 Ohm gate resistor each. Shunts 0.2 mOhm, CSA gain 40 V/V: +-206 A.',
    'Phase and bus sense 39k / 2.2k (as VESC). PC13 switches 10 nF phase filters in (HW_HAS_PHASE_FILTERS).',
    'DC link: 4 x 330 uF 35 V hybrid polymer (12.8 mm tall: clears the brain board NVMe) + 12 x 10 uF 1210 ceramics.',
    'E-stop: DRV ENABLE = PB5 AND the E-stop loop (74LVC1G08), so an open loop stops the gates with no firmware.',
])
d.chip('U', DRV8323RS, {
    'VM': 'VM', 'VDRAIN': 'VM', 'VCP': 'DRV_VCP', 'CPH': 'DRV_CPH', 'CPL': 'DRV_CPL', 'DVDD': 'DRV_DVDD', 'VREF': '+3V3',
    'INHA': 'PWM_AH', 'INLA': 'PWM_AL', 'INHB': 'PWM_BH', 'INLB': 'PWM_BL', 'INHC': 'PWM_CH', 'INLC': 'PWM_CL',
    'ENABLE': 'DRV_EN', 'CAL': 'DRV_CAL', 'nSCS': 'DRV_CS_N', 'SCLK': 'DRV_SCK', 'SDI': 'DRV_MOSI', 'SDO': 'DRV_MISO',
    'nFAULT': 'DRV_FAULT_N', 'SOA': 'CSA_A', 'SOB': 'CSA_B', 'SOC': 'CSA_C',
    'VIN': 'BUCK_VIN', 'nSHDN': 'BUCK_EN', 'CB': 'BUCK_CB', 'SW': 'BUCK_SW', 'FB': 'BUCK_FB',
    'GHA': 'GHA', 'SHA': 'PHA', 'GLA': 'GLA', 'SPA': 'SPA', 'SNA': 'SNA',
    'GHB': 'GHB', 'SHB': 'PHB', 'GLB': 'GLB', 'SPB': 'SPB', 'SNB': 'SNB',
    'GHC': 'GHC', 'SHC': 'PHC', 'GLC': 'GLC', 'SPC': 'SPC', 'SNC': 'SNC', 'NC': None, 'GND': 'GND'})
d.C('C', '100n 50V', 'VM', 'GND', desc='CVM1')
d.C('C', '10u 50V', 'VM', 'GND', size='1210', mpn=MUR_10U50, desc='CVM2')
d.C('C', '1u 25V', 'DRV_VCP', 'VM', size='0603', desc='CVCP')
d.C('C', '47n 50V', 'DRV_CPH', 'DRV_CPL', size='0603', desc='CSW charge pump flying cap')
d.C('C', '1u 6.3V', 'DRV_DVDD', 'GND', desc='CDVDD')
d.C('C', '100n', '+3V3', 'GND', desc='CVREF')
d.R('R', '10k', '+3V3', 'DRV_FAULT_N', desc='nFAULT pull-up')
d.R('R', '10k', '+3V3', 'DRV_MISO', desc='SDO pull-up')
d.R('R', '10k', '+3V3', 'DRV_CS_N', desc='nSCS idle high during MCU reset')
d.R('R', '100k', 'DRV_EN', 'GND', desc='gate drive off by default')
for k, ph in enumerate('ABC'):
    n = 54 + k * 12
    # current sense output filters to the ADC
    d.R('R', '100', f'CSA_{ph}', f'CURR_{ph}', desc='CSA output filter')
    d.C('C', '1n', f'CURR_{ph}', 'GND', desc='CSA output filter')
    # phase voltage divider and switched filter
    d.R('R', '39k', f'PH{ph}', f'SENS_{ph}', desc='phase sense divider top (VESC 39k / 2.2k)')
    d.R('R', '2.2k', f'SENS_{ph}', 'GND', desc='phase sense divider bottom')
    d.C('C', '10n', f'SENS_{ph}', f'PHF_{ph}', desc='phase filter cap, switched by PC13')
    d.chip('Q', NMOS_SOT23, {'G': 'PHASE_FILT', 'D': f'PHF_{ph}', 'S': 'GND'}, desc='phase filter switch')
    # gate resistors and FETs, two per switch
    for j in range(2):
        d.R('R', '2.2', f'GH{ph}', f'GH{ph}{j}', desc='high-side gate resistor')
        d.R('R', '2.2', f'GL{ph}', f'GL{ph}{j}', desc='low-side gate resistor')
        d.chip('Q', NFET_Q5B, {'G': f'GH{ph}{j}', 'D': 'VM', 'S': f'PH{ph}'}, side='B',
               desc=f'phase {ph} high-side FET')
        d.chip('Q', NFET_Q5B, {'G': f'GL{ph}{j}', 'D': f'PH{ph}', 'S': f'PH{ph}_LS'}, side='B',
               desc=f'phase {ph} low-side FET')
    d.chip('R', SHUNT4, {'I1': f'PH{ph}_LS', 'I2': 'GND', 'S1': f'SP{ph}', 'S2': f'SN{ph}'}, value='0.2m', side='B',
           mpn='BVR-Z-R0002-1.0', mfr='Isabellenhuette', desc=f'phase {ph} low-side shunt 0.2 mOhm')
    for j in range(4):
        d.C('C', '10u 50V', 'VM', 'GND', size='1210', mpn=MUR_10U50, desc='DC link ceramic at the half-bridge')
    PADM = 'atlas:WirePad_SMD_9x7mm_10Vias'
    d.chip('J', conn(f'PAD_MOTOR_{ph}', 1, PADM, desc=f'motor phase {ph}, 12 AWG pigtail'), {'1': f'PH{ph}'},
           value=f'MOTOR {ph}', in_bom='no')
for i in range(4):
    d.CP('C', '330u 35V', 'VM', 'GND', 'Capacitor_SMD:CP_Elec_10x10', mpn='EEH-ZU1V331P', mfr='Panasonic',
         desc='DC link bulk, hybrid polymer 330 uF 35 V, 10 x 12.8 mm, 11 mOhm, 4.8 A rms (100 kHz, 125 C)')
d.R('R', '39k', 'VM', 'VIN_SENSE', desc='bus voltage divider (VIN_R1)')
d.R('R', '2.2k', 'VIN_SENSE', 'GND', desc='bus voltage divider (VIN_R2)')
d.C('C', '10n', 'VIN_SENSE', 'GND', desc='bus sense filter')
d.stock('TH', 'Device:Thermistor_NTC', '10k B3380', 'Resistor_SMD:R_0402_1005Metric', {'1': '+3V3', '2': 'TEMP_PCB'}, side='B',
        mpn='NCP15XH103F03RC', mfr='Murata', desc='FET temperature, 10k B25/50 3380 (VESC NTC_TEMP)')
d.R('R', '10k', 'TEMP_PCB', 'GND', desc='NTC divider')
d.C('C', '100n', 'TEMP_PCB', 'GND', desc='NTC filter')
# E-stop
d.chip('U', LVC1G08, {'VCC': '+3V3', 'A': 'GATE_EN_MCU', 'B': 'ESTOP_OK', 'Y': 'DRV_EN', 'GND': 'GND'})
d.C('C', '100n', '+3V3', 'GND', desc='AND gate decoupling')
d.chip('J', conn('ESTOP', 2, 'Connector_JST:JST_PH_B2B-PH-K_1x02_P2.00mm_Vertical', mpn='B2B-PH-K-S(LF)(SN)', mfr='JST',
                   desc='E-stop loop, normally closed'), {'1': 'ESTOP_SRC', '2': 'ESTOP_IN'})
d.R('R', '1k', '+3V3', 'ESTOP_SRC', desc='loop source current limit')
d.R('R', '100', 'ESTOP_IN', 'ESTOP_OK', desc='loop filter')
d.R('R', '10k', 'ESTOP_OK', 'GND', desc='open loop reads low = stop')
d.C('C', '100n', 'ESTOP_OK', 'GND', desc='loop filter')
d.D('D', 'PESD5V0S1BA', 'GND', 'ESTOP_IN', 'Diode_SMD:D_SOD-323', kind='TVS', mpn='PESD5V0S1BA', mfr='Nexperia',
    desc='ESD on the external loop')
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

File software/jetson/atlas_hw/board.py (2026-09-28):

"""Where the drive board and brain board parts sit, as the Jetson sees them.

Sources: boards/stack/stack.py (stack pin map), boards/brain/out/atlas_brain.net (module pins), the
Linux device trees for the Orin Nano (tegra234.dtsi aliases: i2c1 = gen2 at 0xc240000, i2c7 = gen8
at 0xc250000) and the Orin Nano 40-pin header tables (module I2C0 on pins 185/187 is /dev/i2c-1,
module I2C1 on pins 189/191 is /dev/i2c-7, module UART1 on pins 203/205 is serial@3100000).

Bus numbers are looked up by controller address at run time, so a different numbering in a
later JetPack does not break anything. ATLAS_I2C_STACK, ATLAS_I2C_SYS and ATLAS_VESC_TTY override.
"""
import glob
import os

# Module I2C1 (pins 189/191) -> stack pins 19/20 -> drive board
STACK_I2C_CONTROLLER = 'c250000.i2c'
STACK_I2C_DEFAULT = 7
INA228_ADDR = 0x40          # drive board, BMS shunt 0.5 mOhm, pack voltage on B+
ID_EEPROM_ADDR = 0x50       # drive board 24AA02, WP tied low (it answers on all of 0x50-0x57)
TPS25751_ADDR = 0x20        # drive board PD controller target port (ADCIN1 = LDO_3V3, ADCIN2 = GND: index #1)
TPS23861_ADDR = 0x28        # brain board PoE PSE (A3 open); every TPS23861 also answers 0x30 (broadcast)

# Module I2C0 (pins 185/187) -> brain board "SYS I2C": the expander (and the module's own INA3221 at 0x40)
SYS_I2C_CONTROLLER = 'c240000.i2c'
SYS_I2C_DEFAULT = 1
EXPANDER_ADDR = 0x20        # PCAL6408A U34, ADDR strapped to GND

# Module UART1 (pins 203/205) -> NTS0102 -> stack pins 15/16 -> STM32 USART3 (VESC, 115200)
VESC_UART_CONTROLLER = '3100000.serial'

# Expander lines (fork_config.py RENAME_GLOBAL, peripherals sheet)
EXP_MCU_RST_REQ = 0     # out: 1 = hold the STM32 in reset (Q1003 pulls NRST low)
EXP_MCU_BOOT0 = 1       # out: 1 = STM32 starts its ROM bootloader at the next reset
EXP_LIDAR_EN = 2        # out: 1 = lidar eFuse (TPS26600) on
EXP_ESTOP_OK = 3        # in:  1 = E-stop loop closed
EXP_CHG_STAT_N = 4      # in:  0 = charging (BQ25798 STAT through 10k)
EXP_SPARE1 = 5          # stack pin 31, test pad on the drive board
EXP_SPARE2 = 6          # stack pin 32
EXP_PSE_INT_N = 7       # in:  0 = PoE controller interrupt
EXP_OUTPUTS = (1 << EXP_MCU_RST_REQ) | (1 << EXP_MCU_BOOT0) | (1 << EXP_LIDAR_EN)

# Battery pack: 4S3P Molicel P28A
PACK_CELLS_SERIES = 4
PACK_CAPACITY_AH = 8.4
BMS_SHUNT_OHM = 0.0005


def _find_i2c_bus(controller, env, default):
    if os.environ.get(env):
        return int(os.environ[env])
    for path in glob.glob('/sys/bus/i2c/devices/i2c-*'):
        real = os.path.realpath(path)
        if f'/{controller}/' in real + '/':
            try:
                return int(os.path.basename(path).split('-')[1])
            except ValueError:
                pass
    return default


def stack_i2c_bus():
    """Linux bus number of the stack I2C (INA228, ID EEPROM, TPS25751, TPS23861)."""
    return _find_i2c_bus(STACK_I2C_CONTROLLER, 'ATLAS_I2C_STACK', STACK_I2C_DEFAULT)


def sys_i2c_bus():
    """Linux bus number of the brain board SYS I2C (PCAL6408A expander)."""
    return _find_i2c_bus(SYS_I2C_CONTROLLER, 'ATLAS_I2C_SYS', SYS_I2C_DEFAULT)


def vesc_tty():
    """The tty that reaches the STM32 (VESC firmware), e.g. /dev/ttyTHS0."""
    if os.environ.get('ATLAS_VESC_TTY'):
        return os.environ['ATLAS_VESC_TTY']
    if os.path.exists('/dev/atlas_vesc'):
        return '/dev/atlas_vesc'
    for path in sorted(glob.glob('/sys/class/tty/ttyTHS*')):
        if VESC_UART_CONTROLLER in os.path.realpath(os.path.join(path, 'device')):
            return '/dev/' + os.path.basename(path)
    return '/dev/ttyTHS0'

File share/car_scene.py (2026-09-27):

"""Whole-car scene for the renders: the printed kit and the parts that finish it (mech/kit.py, mech/extras.py),
both boards (their KiCad 3D models), every cable, and stand-ins for everything bought.

    python3 share/car_scene.py          writes share/scene/*.stl and share/scene/scene.json (about 1 minute)
    share/render_car.sh                 renders them with Blender Cycles (render_car.py)

The stand-ins are NOT models of the real parts. They are drawn from the sizes this design already uses: the
Traxxas Slash 4x4 from kit.py's chassis keep-out numbers (all estimates, docs/MEASURE_FIRST.md), the SICK TiM561
and LUCID Triton from their datasheet envelopes in kit.py, the Jetson module with the dev kit's heatsink and fan
from its 69.6 x 45 mm module and kit.py's 32 mm height. Suspension geometry, wheel spokes, tread, fins and fan
blades are drawn to look right, not measured.

Units are mm in the car frame of kit.py (+x forward, +y left, +z up, deck top at z 0).
"""
import json
import math
import os
import sys

import cadquery as cq

HERE = os.path.dirname(os.path.abspath(__file__))
ROOT = os.path.dirname(HERE)
sys.path.insert(0, os.path.join(ROOT, 'mech'))
import kit  # noqa: E402
import extras  # noqa: E402
from kit import P, box, cylz, cyl, union  # noqa: E402

SCENE = os.path.join(HERE, 'scene')
os.makedirs(SCENE, exist_ok=True)

OBJ = []            # (name, shape, material, group)


def add(name, shape, mat, group):
    OBJ.append((name, shape, mat, group))


def comp(*shapes):
    """compound without boolean union (fine for rendering, much faster)"""
    sol = []
    for s in shapes:
        if s is None:
            continue
        v = s.vals() if hasattr(s, 'vals') else [s]
        for x in v:
            sol.extend(x.Solids() if hasattr(x, 'Solids') else [x])
    return cq.Workplane('XY').add(cq.Compound.makeCompound(sol))


def cyl_between(p0, p1, d):
    L = math.dist(p0, p1)
    v = tuple((p1[i] - p0[i]) / L for i in range(3))
    return cq.Workplane('XY').add(cq.Solid.makeCylinder(d / 2, L, cq.Vector(*p0), cq.Vector(*v)))


def rot_y_axis(shape, center, deg):
    return shape.rotate(center, (center[0], center[1] + 1, center[2]), deg)


# ----------------------------------------------------------------------------- chassis stand-in (Slash 4x4)
Z_RIM, Z_FLOOR, TOWER_TOP = kit.Z_RIM, kit.Z_FLOOR, kit.TOWER_TOP
R_TYRE = P['TYRE_D'] / 2
Y_TYRE = P['TRACK'] / 2 - P['TYRE_W'] / 2                  # tyre centre plane
Z_AXLE = Z_RIM + P['TYRE_TOP_ABOVE_RIM'] - R_TYRE           # -89.175
Z_GROUND = Z_AXLE - R_TYRE                                  # -144.175
AXLES = {'front': kit.FRONT_AXLE, 'rear': kit.REAR_AXLE}


def wheel_parts(xc, sy):
    """rim, tyre carcass and lugs for one corner, placed. Built about the origin with the axle along y."""
    W = P['TYRE_W']
    yc = sy * Y_TYRE
    # carcass: revolve a profile drawn in the XY plane (x = radius, y = axial) about the y axis
    r_in, r_out = 35.0, R_TYRE - 3.0
    pts = [(r_in, -W / 2 + 3), (r_out - 7, -W / 2 + 1), (r_out - 1.5, -W / 2 + 4), (r_out, -W / 2 + 9),
           (r_out, W / 2 - 9), (r_out - 1.5, W / 2 - 4), (r_out - 7, W / 2 - 1), (r_in, W / 2 - 3)]
    carcass = cq.Workplane('XY').polyline(pts).close().revolve(360, (0, 0, 0), (0, 1, 0))
    lugs = []
    n = 26
    for yoff, phase in ((-10.0, 0.0), (10.0, 0.5)):
        for i in range(n):
            a = 360.0 * (i + phase) / n
            lug = box(-4.2, 4.2, -7.5, 7.5, r_out - 0.6, R_TYRE)
            lugs.append(lug.translate((0, yoff, 0)).rotate((0, 0, 0), (0, 1, 0), a))
    for i in range(n):                                          # shoulder blocks on the sidewall edge
        a = 360.0 * (i + 0.25) / n
        for s in (-1, 1):
            sb = box(-3.0, 3.0, s * (W / 2 - 3.0) - 2.0, s * (W / 2 - 3.0) + 2.0, r_out - 5.0, r_out + 1.0)
            lugs.append(sb.rotate((0, 0, 0), (0, 1, 0), a))
    # rim: barrel, outer lip, 6 split spokes, hub with a wheel nut
    rim_r = r_in + 1.0
    barrel = cq.Workplane('XZ').circle(rim_r).circle(rim_r - 2.5).extrude(W - 6).translate((0, W / 2 - 3, 0))
    lip = cq.Workplane('XZ').circle(rim_r + 2.2).circle(rim_r - 2.5).extrude(3).translate((0, W / 2, 0))
    face_y = W / 2 - 4.0
    spokes = []
    for i in range(6):
        for d in (-7.0, 7.0):
            a = 60.0 * i + d
            s = box(8.0, rim_r - 1.0, -2.5, 2.5, -2.2, 2.2).translate((0, face_y, 0))
            spokes.append(s.rotate((0, 0, 0), (0, 1, 0), a))
    hub = cq.Workplane('XZ').circle(12.0).extrude(10).translate((0, face_y + 2.5, 0))
    nut = cq.Workplane('XZ').polygon(6, 10.0).extrude(6).translate((0, face_y + 8.5, 0))
    if sy < 0:
        mirror = lambda s: s.mirror('XZ')                     # noqa: E731
        carcass, lugs = mirror(carcass), [mirror(l) for l in lugs]
        barrel, lip, spokes, hub, nut = mirror(barrel), mirror(lip), [mirror(s) for s in spokes], mirror(hub), mirror(nut)
    place = lambda s: s.translate((xc, yc, Z_AXLE))           # noqa: E731
    return (place(carcass), [place(l) for l in lugs], place(comp(barrel, lip, *spokes, hub)), place(nut))


def coilover(top, bottom, body_d=16.0, spring_d=19.0):
    """shock: body from the top mount, rod to the bottom mount, a coil spring over the body"""
    L = math.dist(top, bottom)
    v = tuple((bottom[i] - top[i]) / L for i in range(3))
    at = lambda s: tuple(top[i] + v[i] * s for i in range(3))  # noqa: E731
    body = cyl_between(at(4), at(0.62 * L), body_d)
    cap = cyl_between(at(0), at(6), body_d + 2)
    rod = cyl_between(at(0.62 * L), at(L - 4), 5.0)
    eye_t = cyl_between(at(-3), at(5), 8.0)
    eye_b = cyl_between(at(L - 6), at(L + 2), 8.0)
    # spring: a helix swept with a circle
    turns, pitch = 7, (0.62 * L - 10) / 7
    helix = cq.Wire.makeHelix(pitch, pitch * turns, spring_d / 2 - 1.2)
    spring = (cq.Workplane('XY').add(cq.Solid.makeSphere(0.1)))
    try:
        path = cq.Workplane('XY').add(helix)
        prof = cq.Workplane('XZ').center(spring_d / 2 - 1.2, 0).circle(1.2)
        spring = prof.sweep(path, isFrenet=True)
        # helix is along +z from the origin: orient it along the shock, starting 8 mm below the top
        z = cq.Vector(0, 0, 1)
        d = cq.Vector(*v)
        ax = z.cross(d)
        ang = math.degrees(math.acos(max(-1, min(1, z.dot(d)))))
        if ax.Length > 1e-9:
            spring = spring.rotate((0, 0, 0), ax.toTuple(), ang)
        spring = spring.translate(at(8))
    except Exception:
        spring = cyl_between(at(8), at(0.62 * L), spring_d)
    return comp(body, cap, eye_t), comp(rod, eye_b), spring
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

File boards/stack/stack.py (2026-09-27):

"""The drive-board-to-brain-board connector, defined once for both boards.

Both board generators import this file, so the pin map, the net names and the pin positions
cannot drift apart. tools/check_stack.py reads the netlists and footprints of both finished
boards and checks them against this table.

Coordinates are board-local, top view, in mm: X runs forward from each board's rear edge,
Y runs toward the car's left side from each board's right edge. The brain board sits 20 mm
further forward, so brain X = drive X - 20 and brain Y = drive Y.
"""

PITCH = 2.54
COLS = 20                      # 2 x 20, pin 1 at the rear end
CENTER_DRIVE = (85.5, 62.5)    # header centre on the drive board (from the placement plan)
BRAIN_DX = -20.0               # brain-local X = drive-local X + BRAIN_DX
STACK_GAP = 20.0               # drive-board top to brain-board bottom (mech/kit.py STACK_H): 20 mm M3 standoffs;
                               # the brain NVMe then clears the drive's 12.8 mm bulk caps by about 2 mm

# pin: (net, kind, direction, note). kind: pwr / gnd / sig. Direction is seen from the drive board.
PINS = {
    1: ('VSYS', 'pwr', 'out', 'charger SYS rail, 12-16.8 V; 6 pins x 3 A'),
    2: ('VSYS', 'pwr', 'out', ''),
    3: ('VSYS', 'pwr', 'out', ''),
    4: ('VSYS', 'pwr', 'out', ''),
    5: ('VSYS', 'pwr', 'out', ''),
    6: ('VSYS', 'pwr', 'out', ''),
    7: ('GND', 'gnd', '', ''),
    8: ('GND', 'gnd', '', ''),
    9: ('GND', 'gnd', '', ''),
    10: ('GND', 'gnd', '', ''),
    11: ('STK_USB0_DP', 'sig', 'bidi', 'Jetson USB0 D+ (hub port 1, or straight to USB-C when flashing)'),
    12: ('STK_USB0_DN', 'sig', 'bidi', 'Jetson USB0 D-'),
    13: ('GND', 'gnd', '', ''),
    14: ('GND', 'gnd', '', ''),
    15: ('STK_VESC_J2M', 'sig', 'in', 'Jetson UART1 TX -> STM32 USART3 RX (PB11), 3.3 V'),
    16: ('STK_VESC_M2J', 'sig', 'out', 'STM32 USART3 TX (PB10) -> Jetson UART1 RX, 3.3 V'),
    17: ('STK_CON_J2M', 'sig', 'in', 'Jetson debug UART TX -> CP2102N RXD, 3.3 V'),
    18: ('STK_CON_M2J', 'sig', 'out', 'CP2102N TXD -> Jetson debug UART RX, 3.3 V'),
    19: ('STK_I2C_SCL', 'sig', 'bidi', 'Jetson I2C1 (3.3 V, pulled up on the module): INA228 0x40, ID EEPROM 0x50, TPS25751 target'),
    20: ('STK_I2C_SDA', 'sig', 'bidi', ''),
    21: ('STK_PWR_BTN_N', 'sig', 'out', 'low while the power button asks the Jetson to shut down (module SLEEP/WAKE*)'),
    22: ('STK_OS_HALTED', 'sig', 'in', 'high when the Jetson module is off; pulled up on the drive board'),
    23: ('STK_POWER_EN', 'sig', 'out', 'high = brain board input eFuse on; pulled down on the brain board'),
    24: ('STK_MCU_NRST', 'sig', 'in', 'open drain from the brain board (FET on expander P0): resets the STM32'),
    25: ('STK_MCU_BOOT0', 'sig', 'in', 'expander P1 drives high to start the STM32 bootloader'),
    26: ('STK_ESTOP_OK', 'sig', 'out', 'high while the E-stop loop is closed (expander P3 input)'),
    27: ('STK_CHG_STAT', 'sig', 'out', 'BQ25798 STAT, open drain via 10k, low while charging (expander P4 input)'),
    28: ('STK_LIDAR_EN', 'sig', 'in', 'high = lidar eFuse on (expander P2); pulled down on the drive board'),
    29: ('GND', 'gnd', '', ''),
    30: ('GND', 'gnd', '', ''),
    31: ('STK_SPARE1', 'sig', 'bidi', 'brain board I/O expander pin (PCAL6408A P5, 3.3 V); test pad on the drive board'),
    32: ('STK_SPARE2', 'sig', 'bidi', 'expander P6'),
    33: ('STK_CAN_TX', 'sig', 'in', 'Jetson CAN TX (3.3 V); test pad on the drive board'),
    34: ('STK_CAN_RX', 'sig', 'out', 'Jetson CAN RX (3.3 V)'),
    35: ('3V3_DRV', 'pwr', 'out', 'drive board 3.3 V: reference rail for the brain board level shifters'),
    36: ('GND', 'gnd', '', ''),
    37: ('GND', 'gnd', '', ''),
    38: ('GND', 'gnd', '', ''),
    39: ('GND', 'gnd', '', ''),
    40: ('GND', 'gnd', '', ''),
}
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

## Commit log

2026-09-27 Car v2: drive board, brain board, printed kit, simulations
    The second Atlas car on the Traxxas Slash 4x4, designed so almost nothing is wired by hand:
    - ATLAS-DRV-1 drive board (6 layers): VESC-class ESC, BMS for a built-in 4S3P 18650
    pack, USB-C PD charging, USB hub and console, servo and lidar supplies. Routed; DRC
    shows no unconnected nets and no clearance errors.
    - ATLAS-BRN-1 brain board (8 layers): Jetson Orin carrier forked from Antmicro's
    baseboard, with PoE for the camera and a second Ethernet port for the lidar. Routed;
    DRC shows no unconnected nets and no clearance errors.
    - Fabrication files, stack header check, circuit and thermal simulations, the printed
    PETG-CF kit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
    [assembly_kit_and_components.step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]
2026-09-27 Review fixes: docs, run_kicad.sh and drive board text
    - README, docs/ARCHITECTURE.md, share/README.md, boards/tools/README.md: status,
    rebuild steps and tool notes brought up to date
    - run_kicad.sh: the optional first argument is a sync tarball or an empty string
    - Drive schematic text: header J702, 7.5 V servo rail, the precharge resistors
    take 0.15 J each (R319/R320 descriptions synced on the board)
    - BOM wording: 7.5 V servo rail
    DRC unchanged: no unconnected items, no clearance errors, 8 silkscreen and
    track-end warnings.
    Claude-Session: https://claude.ai/code/session_01XVBHou86msuHYBGRPr641F
    [atlas_drive.kicad_pcb, atlas_drive.kicad_sch, atlas_drive_c_switch.kicad_sch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]
2026-09-27 Whole car: canopy, bench stand, every cable, and Blender renders
    - mech/extras.py (new): the stack canopy (antenna jacks, fan grille), a
    wheels-off bench stand, the RJ45 plugs, and 14 cable runs as paths through
    the model. Checked against the kit: no interference, and everything that
    crosses the lidar scan plane sits in its rear blind sector.
    - mech/kit.py: two fixes the plugs and cables turned up. The right pod's fan
    moved forward (x -16 to 24) and the pod has a slot for the camera's RJ45
    plug; the deck's servo-lead slot moved off the front splice plate and its
    bolt (x 98.5 to 103.5).
    - docs: COMPLETE_CAR.md, WIRING.md (every run, routed length, length to
    cut), MEASURE_FIRST.m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
    [assembly_kit_and_components.step, bench_stand.step, bench_stand.stl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]
2026-09-27 Finishing parts: the products on the Syslab order
    The canopy antennas, pigtails, standoffs and E-stop lead went to Dr. Yilmaz
    as items 13-16 of the Syslab order, and to Eshan's rows on the purchase
    sheet. The BOM now names those Amazon listings and their prices: $29.36 in
    all, car total $1,951.15, phase 1 $1,366.88. Zip ties come from the lab.
    - The dev kit's Wi-Fi card (AzureWave AW-CB375NF) has MHF4 jacks per its
    datasheet, so the pigtails are MHF4 to RP-SMA, 15 cm.
    - extras.py: the antenna is 120 mm (the Bingfu listing), up from 108.
    Rerun: still no interference, and the antennas stay in the lidar's blind
    sector.
    Claude-Sessi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
    [bom.csv, bought_antennas.step, cost_summary.csv]
2026-09-28 Software for the car v2 boards: VESC target that builds, Jetson tools, flashing docs
    Drive board STM32 (firmware/vesc):
    - hw_atlas_drv1.c/.h rewritten so the target compiles on VESC 6.06 and the power
    logic holds up: precharge with short detection and no endless retry, DRV8323RS
    settings restored after every E-stop, current offsets re-measured when they were
    taken with the gate driver asleep, POWER_EN raised in HW_EARLY_INIT, Jetson
    power-key press and halt detection, clean power-off from the button.
    - build.sh: pinned bldc 6.06 + bootloader, system GCC fallback, 0xFF-filled .bin and
    one .hex with the VESC bootloader for the first SWD flash.
    Jetson (software/jetson): atlas command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
    [battery.py, board.py, cli.py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]
2026-09-28 Prebuilt ATLAS_DRV1 firmware from bf4234f (VESC 6.06, GCC 13.2)
    Claude-Session: https://claude.ai/code/session_01KpDioHi745sUfRY48Q9ZVq
2026-09-28 Review fixes: main-switch trip watch, PD patch address, gate driver and Jetson handling
    Firmware (hw_atlas_drv1):
    - A collapsed motor bus while on (TPS48111 trip) now drops MAIN_ON, so the chip's
    15 s auto-retry cannot close the FETs onto an empty bus; precharge again after
    15 s, three times at most.
    - The DRV8323 is restored as soon as it is powered and enabled (it runs from the
    switched bus), its gain is read back every 5 ms, and the offsets are measured
    again only if the boot calibration ran without the right gain, with
    mc_interface locked instead of a 5 s input hold.
    - Motor hold no longer logs two release events every 5 ms.
    - No automatic power-button press after the Jetson ha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
    [board.py, hw_atlas_drv1.c, hw_atlas_drv1.h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]
2026-09-28 FLASHING.md: the ST-Link on the purchase sheet (STLINK-V3SET, cable for J601 included)
    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
2026-09-29 Add PCBWay silkscreen branding to both boards (Future Innovators Program requirement)
    Drive: vertical 1.6 mm text at (45, 86) in the strip the brain board doesn't cover.
    Brain: 2.0 mm text at (96, 57.25), above the 40-pin header, outside the Jetson module.
    Both spots clear of pads, holes, vias, courtyards and other silkscreen.
    Run DRC and regenerate fab files on the KiCad machine: run_kicad.sh drc-drive fab-drive drc-brain fab-brain
    Claude-Session: https://claude.ai/code/session_01TnZbLRjxD6Vfoy9VM5v47G
    [atlas_brain.kicad_pcb, atlas_drive.kicad_pcb]
2026-09-29 Fab files: PCBWay logo added to both top-silkscreen Gerbers
    Added straight to atlas_drive-F_Silkscreen.gto and atlas_brain-F_Silkscreen.gto (and the zips),
    matching the text placed in the .kicad_pcb files in ed57a2f, because KiCad is not on this computer.
    Checked against the Gerbers: at least 0.15 mm from every mask opening and existing silkscreen.
    Regenerating with run_kicad.sh fab-drive fab-brain on the KiCad machine will replace these with
    KiCad's own rendering of the same text.
    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
    [atlas_brain-F_Silkscreen.gto, atlas_drive-F_Silkscreen.gto]
2026-09-29 Drive board: POWER_EN fix (R609 to +3V3, new R625 pull-down on GATE_EN_MCU)
    Approved by Ragini, Sept 29.
    - R609 (100k) now pulls STK_POWER_EN up to +3V3 instead of down to GND, so the brain board and
    the Jetson stay powered while the STM32 is in reset, being flashed, or blank.
    - R625 (10k, 0402) pulls GATE_EN_MCU (PB5, U502 input A) down, so the gate driver stays off
    while the STM32 is in reset or in its ROM bootloader. Placed on the GATE_EN_MCU track next to
    U502 with its own GND via; placement recorded in out/atlas_drive_placement.json.
    - Layout: R609's GND stub and via taken off. mazeroute.py routed R609 pad 2 to +3V3 (In2, two
    0.5 mm vias) and joined C619's ground (the piece of t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
    [atlas_brain-B_Cu.gbl, atlas_brain-B_Mask.gbs, atlas_brain-B_Paste.gbp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]
2026-09-30 mech: PRINTING.md - print orientations and supports after the bumper failure
    Overhang audit of every STL: bumper, camera arch, pack box, side pods, wing blade and struts
    had large unsupported overhangs in the out/stl orientation. Arch, pack box and pods print
    upside down; bumper, pods, wing, struts, arch and pack box get tree supports from the plate.
    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
2026-10-24 Rev B (WIP): Pico supervisor firmware and Jetson software for the dev-kit carrier
    MicroPython supervisor in firmware/supervisor (JBD BMS link, power sequencer,
    USB-CDC protocol, CPython test harness) and the software/jetson changes for the
    NVIDIA dev-kit carrier (gpio, supervisor client, udev, NetworkManager, services,
    shutdown hook). 172 tests pass on the simulated board; nothing has run on
    hardware yet. Rev A modules are kept under atlas_hw/reva.
    Claude-Session: https://claude.ai/code/session_01BogQQgJLXFQcAbYtKpDqRe
2026-10-24 Rev B (WIP): printed kit for the dev-kit carrier, FSESC bay, BMS fence and the 130 mm power board
    mech/kit.py and extras.py: power board height map and standoffs, dev-kit tray on
    parametric (unmeasured) carrier holes, ESC cradle beside the motor, BMS fence on
    the pack lid, new pod windows, canopy and 31 checked cable runs. Zero
    interference at POWER_L 130. board_outlines.py writes the power outline, holes
    and keep-outs. MEASURE_FIRST items 17-26, WIRING rev B lengths, PRINTING notes.
    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
2026-10-24 Rev B (WIP): ATLAS-PWR-1 power board schematic, parts and placement
    boards/power: design.py (blocks A..J, through-hole ICs, transistors, diodes,
    connectors and power parts; 1206 passives on the bottom), chips_power.py,
    layout.py, netcheck.py (11 operating scenarios, 0 errors), PINMAP.md, README,
    HANDOFF_E. New footprints in boards/lib/atlas.pretty, placer options,
    fp_lib_from_mod.py. bom/revb: parts list and cost (40.67 per board at qty 1).
    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
2026-10-24 Rev B (WIP): REV_B.md architecture, student assembly guide, README and cost summary
    docs/REV_B.md (why rev B, what changed, system diagram, what the car plugs
    into, what is given up, cost table with sources, open measurements, bring-up
    order, rev C list), docs/BUILD_POWER_BOARD.md (assembly by height, polarity
    checks, three bench tests, module set-up, harnesses, sign-off), README rev B
    status, make_bom.py writes the rev A and rev B cost tables.
    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
2026-10-24 Rev B: independent pre-order review (fix first, then order)
    One blocker (charge module current sense bypassed by the shared ground), seven
    majors (level-shifter drive, P-FET gate drive and heat, precharge with real
    loads, heartbeat-loss cut, long-press latch race, FSESC signal grounds carrying
    motor return, high-speed USB over Dupont leads), 22 minors. Fixes are being
    applied to the design and firmware.
    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
2026-10-24 Rev B: supervisor firmware fixes from the review (M3, M4, M5, m7, m8, m16)
    Precharge done at 90 % or within 2.5 V and settled; a lost heartbeat with the
    Jetson up requests a shutdown instead of cutting power; the 5 s press pulses
    the latch only after release; low-pack checks stay active while charging;
    no endless OFF pulses; a press in LOCKOUT with the loop open is refused.
    119 firmware tests and 77 Jetson tests pass; the reviewer's scenarios pass.
    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
2026-10-24 Rev B: laser-cut variants of the flat parts, FET shield, 130 mm board default
    mech/out/laser: DXF and SVG for the dev-kit tray, BMS holder (base and two
    walls), canopy top and skirts, deck splices and an acrylic shield over the
    live FET bar; SHEET_T and SHEET_PARTS parameters, tab and slot rule, cut vs
    print notes in mech/README.md and PRINTING.md. Interference clean with printed
    or sheet parts at POWER_L 130. MEASURE_FIRST items 27-28.
    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
2026-10-24 Rev B: design fixes from the review (B1, M1, M2, M3, M6, M7, minors)
    Charge ground split (CHG_GND, MOD502 OUT- the only tie to GND, netcheck rule
    14); 1 k series into the dev kit's level-shifted inputs; IRF4905PBF with 6.8 k
    dividers and gate caps on the dev-kit and charge P-FETs; BEC+ alternate pad on
    VSYS_SW; series resistors on the FSESC signal grounds; through-hole USB-A for
    the dev kit; R304 2.2 M, C1001 10 nF, P6KE22A on the dev-kit, lidar and camera
    feeds, 10 k NTC series resistor, R408 4.7 ohm; DIP sockets in the BOM; XT90-S
    gender stated. 215 parts, 133 nets, netcheck 0 errors, 49.37 per board.
    Claude-Session: https://claude.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
2026-10-24 Rev B docs: build guide and REV_B.md match the post-review design
    Settings-that-must-be-made table, CC/CV module bench check, corrected test 2,
    test 3 pulse method, new test 4 (real-load precharge), new parts and DIP
    sockets, $149.37 per board and the one-car / two-car totals, the pre-order
    review section, laser-cut option.
    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
2026-10-24 Rev B mech: real connector positions, pod windows, cable lengths
    POWER_CONN and POD_WINDOWS from the final layout; right-angle plug and inner
    window for the dev-kit USB-A J601; charge modules in the pod; camera regulator
    on the arch leg; WIRING.md rev B lengths regenerated; MEASURE_FIRST 29-31.
    Interference and cable checks clean, printed and sheet variants.
    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
2026-10-25 Rev B (WIP): KiCad 7 tool port, netclasses, partly routed ATLAS-PWR-1
    tools/kicompat.py (pcbnew 7 vs 10), drc.py (KiCad 7 has no kicad-cli drc),
    fab_outputs.py, pour_resistance.py, 2-layer pad_vias, Python SES reader;
    board built from the fixed design, USB pairs pre-routed, routing in progress
    (44 unconnected items at this commit). Fab outputs here are from the dry run
    and will be regenerated.
    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
2026-10-26 Rev B (WIP): ATLAS-PWR-1 routing, power paths done, 18 signal nets open
    1869 tracks, 247 vias; BAT, VM, GND, VSYS_SW, servo and gate-drive paths
    hand-routed and locked; mask openings over the BAT and VM pours; pour
    resistance at 90 A: 1.035 mohm end to end (93 mV). 31 unconnected items remain
    around the Pico / J802 header (placement fix pending). PCBWay instant quote
    for 5 boards: $50.09 + $26.55 shipping. hand_routes.py and mazeroute options.
    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
2026-10-26 Rev B: ATLAS-PWR-1 routed on 4 layers, DRC clean, PCBWay fab files
    Two 2-layer attempts left 18-21 logic nets open around the Pico and the J14
    header, so the board is now F.Cu 2 oz (parts, power pours), In1 solid GND
    plane (BMS island cut out), In2 signals, B.Cu 2 oz. 1944 track segments,
    435 vias (317 GND), 0 unconnected, 0 clearance errors. 90 A path 1.035 mohm
    end to end; DEV- return 0.976 mohm. Gerbers (14 files), drill, PCBWay zip,
    CPL, BOM and renders in boards/power/out. PCBWay instant quote, 5 pcs:
    $155.79 + $26.55 shipping (2 oz outer / 1 oz inner).
    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
2026-10-26 Rev B docs: final board facts (4 layers, PCBWay quote, DRC, order files)
    REV_B.md, BUILD_POWER_BOARD.md, README and the cost summary describe the
    finished board: stackup and why four layers, $182.34 for 5 boards shipped,
    per-car totals with the board order included, bottom references on B.Fab,
    KiCad 10 checks to run before ordering.
    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

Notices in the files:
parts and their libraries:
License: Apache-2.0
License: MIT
